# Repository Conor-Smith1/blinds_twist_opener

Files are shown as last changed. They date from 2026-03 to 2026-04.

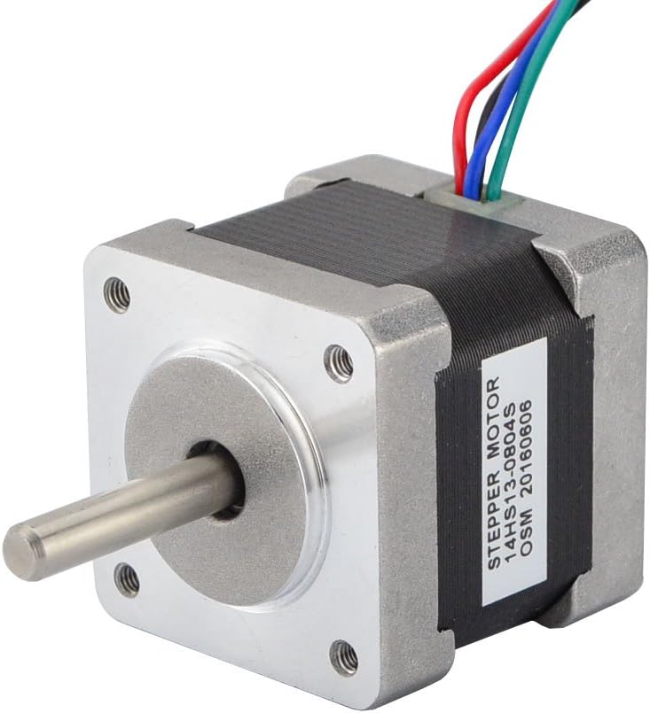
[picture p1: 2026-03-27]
Wiring Diagarm/NEMA14_Stepper.jpg

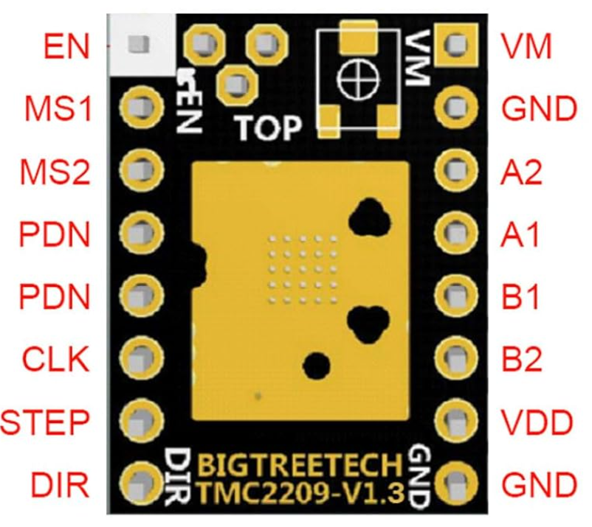
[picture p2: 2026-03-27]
Wiring Diagarm/TMC2209.png

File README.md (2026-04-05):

# Blinds Twist Opener

This project packages the pieces needed to motorize twist-style window blinds with an ESP32, a stepper motor, a hall effect home sensor, and a small 3D-printed enclosure/adapter set. The goal is to automate blinds without permanently modifying an apartment or rental space: the control box can be mounted with removable adhesive, and the printed coupler drives the existing blind wand/shaft.

## What is in this repository

- [`smartblinds.yaml`](smartblinds.yaml): ESPHome firmware for the ESP32, including homing, open/close/position control, and Home Assistant entities.
- [`3D Printer Models`](3D%20Printer%20Models): Printable `.stl` files for the enclosure and blind interface parts.
- [`CAD`](CAD): Source `.step` files for the printable parts.
- [`Wiring Diagarm`](Wiring%20Diagarm): WireViz source plus exported wiring images and reference photos.
- [`BoM.xlsx`](BoM.xlsx): Bill of materials with example parts and source links.

## Hardware overview

The included BOM and wiring files point to a build based on:

- ESP32 dev board
- TMC2209 stepper driver
- NEMA 14 bipolar stepper motor
- A3144 hall effect sensor
- 12 V power supply
- MP1584EN buck converter to power the ESP32
- 220 uF capacitor across the motor supply
- 10 mm x 3 mm magnet for homing
- 1/4 in aluminum rod plus jumper wiring

The spreadsheet title is "Home Assistant Ready Automated Twist Blind Opener", and the example parts list uses readily available hobby components rather than custom electronics.

## Wiring and pin map

The wiring diagram in [`Wiring Diagarm/smart_blinds_wireviz.yml`](Wiring%20Diagarm/smart_blinds_wireviz.yml) maps the ESP32 like this:

- `GPIO25`: motor enable
- `GPIO26`: step
- `GPIO27`: direction
- `GPIO33`: hall effect sensor output
- `3V3` / `GND`: hall sensor power
- `5V` / `GND`: ESP32 power from the buck converter

Power is split two ways:

- 12 V directly to the stepper driver motor supply (`VMOT` + `GND`)
- 12 V into the buck converter, reduced to 5 V for the ESP32

The motor driver is shown as a TMC2209, but the ESPHome config uses the `a4988` stepper platform. That is reasonable here because ESPHome is only generating `STEP`, `DIR`, and `EN` signals; the TMC2209 is effectively being treated like a standalone step/dir driver rather than configured over UART.

## Firmware behavior

The ESPHome config creates:

- A `cover` entity named `Bedroom Blinds`
- A `binary_sensor` named `Blind Home Sensor`
- A `sensor` named `Blind Position Percent`
- Buttons for `Home Blinds`, `Open One Turn`, and `Close One Turn`

On boot, the device automatically runs a homing script:

1. The motor is enabled.
2. The stepper position is seeded to a positive value.
3. The firmware searches toward the hall sensor in small negative moves.
4. Once the sensor triggers, it backs off by a configured close offset.
5. Position `0` is recorded as the fully closed reference point.

If homing never finds the sensor within the allowed travel window, the firmware sets a failure flag and stops the motor.

## Important tuning values

These values in [`smartblinds.yaml`](smartblinds.yaml) will likely need to be adjusted for your blinds and gearing:

- `steps_per_turn: 1600`
- `total_steps: 8000`
- `close_offset_steps: 2400`
- `max_speed: 1200 steps/s`
- `acceleration: 400`
- `deceleration: 400`

What they mean:

- `steps_per_turn`: how many motor steps make one full twist of the blind mechanism
- `total_steps`: full travel from closed to open
- `close_offset_steps`: how far to move after the hall sensor is detected so the blinds land on the true closed position

## How to use the ESPHome config

1. Copy or edit [`smartblinds.yaml`](smartblinds.yaml).
2. Replace the Wi-Fi placeholders with your SSID and password.
3. Update or remove the `manual_ip` block if it does not match your network.
4. Flash the ESP32 with ESPHome.
5. Verify the hall sensor polarity and motor direction before letting the blinds run a full cycle.
6. Tune `steps_per_turn`, `total_steps`, and `close_offset_steps` until the physical open/close positions match the reported cover position.

If the motor moves away from home during startup, reverse the motor direction in firmware or swap the appropriate motor wiring at the driver.

## Files you will probably want first

- Use [`smartblinds.yaml`](smartblinds.yaml) if you are building or modifying the firmware.
- Use [`Wiring Diagarm/smart_blinds_wireviz.svg`](Wiring%20Diagarm/smart_blinds_wireviz.svg) or [`Wiring Diagarm/smart_blinds_wireviz.png`](Wiring%20Diagarm/smart_blinds_wireviz.png) during assembly.
- Use the `.stl` files in [`3D Printer Models`](3D%20Printer%20Models) to print parts directly.
- Use the `.step` files in [`CAD`](CAD) if you want to modify the mechanical design.
- Use [`BoM.xlsx`](BoM.xlsx) if you want the original parts list and purchase references.

## Notes and assumptions

- The repository currently documents a single blind setup named `Bedroom Blinds`; you will probably want to rename entities for your room/device.
- The hall sensor input is configured with pull-up and inverted logic, with 20 ms debounce on both edges.
- The motor enable output is also inverted in firmware.
- This design appears intended for tilt/twist blinds, not lift-style blinds that raise and lower the whole shade.

## License

See [`LICENSE`](LICENSE).

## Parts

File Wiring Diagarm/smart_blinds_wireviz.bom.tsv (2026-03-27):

Id | Description | Qty | Unit | Designators
1 | Cable, 2 wires | 0 | m
2 | Cable, 3 wires | 0 | m
3 | Cable, 4 wires | 0 | m
4 | Cable, 5 wires | 0 | m
5 | Connector, 12V Power Supply, 2 pins | 1 |  | PSU_12V
6 | Connector, A3144 Hall Sensor, 3 pins | 1 |  | Hall_A3144
7 | Connector, ESP32 Dev Board, 7 pins | 1 |  | ESP32
8 | Connector, Electrolytic Capacitor, 2 pins | 1 |  | VMOT_Cap
9 | Connector, MP1584EN Buck Converter, 4 pins | 1 |  | Buck
10 | Connector, NEMA 14 Stepper Motor, 4 pins | 1 |  | Stepper
11 | Connector, TMC2209 Stepper Driver, 10 pins | 1 |  | TMC2209

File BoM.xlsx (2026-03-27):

Home Assistant Ready Automated Twist Blind Opener
Bill of Materials
Item # | ASIN | Product Title | Category | Short Description | Qty Used | Listing / Pack Qty | Source
1 | B01EV70C78 | ELEGOO 120pcs Multicolored Dupont Wire 40pin Male to Female, 40pin Male to Male, 40pin Female to Female Breadboard Jumper Ribbon Cables Kit Compatible with Arduino Projects | Jumper wires | 120-piece jumper wire kit; includes 40-pin male-to-female, male-to-male, and female-to-female ribbons; approx. 20 cm / 8 in each. | 30 | 120 pcs kit | https://www.amazon.com/dp/B01EV70C78?ref=ppx_yo2ov_dt_b_fed_asin_title
2 | B08D5ZD528 | ESP-WROOM-32 ESP32 ESP-32S Development Board 2.4GHz Dual-Mode WiFi + Bluetooth Dual Cores Microcontroller Processor Integrated with Antenna RF AMP Filter AP STA Compatible with Arduino IDE (3PCS) | Microcontroller board | ESP32 development board listing; 2.4 GHz Wi‑Fi + Bluetooth, dual core, Arduino IDE compatible. | 1 | 3 pcs | https://www.amazon.com/dp/B08D5ZD528?ref=ppx_yo2ov_dt_b_fed_asin_title&th=1
3 | B09S5SMFY4 | TRYMAG Small 10x3mm Rare Earth Magnets, 50Pcs Strong Neodymium Tiny Round Fridge Magnets for Whiteboard, Refrigerator, DIY, Kitchen, Office | Magnets | Neodymium round magnets, 10 mm diameter x 3 mm thick. | 1 | 50 pcs | https://www.amazon.com/dp/B09S5SMFY4?ref=ppx_yo2ov_dt_b_fed_asin_title&th=1
4 | B08SMDY3SQ | BIGTREETECH TMC2209 V1.3 UART Stepper Motor Driver 2.8A Peak Stepstick Silent Driver for Manta M8P, Octopus V1.1, Octopus Pro, SKR 3, SKR V1.4 Turbo, SKR Pro V1.2 3D Printer Control Board (2 PCS) | Stepper motor driver | TMC2209 V1.3 UART stepper driver; supports STEP/DIR and UART mode; 2.8 A peak listing. | 1 | 2 pcs | https://www.amazon.com/dp/B08SMDY3SQ?ref=ppx_yo2ov_dt_b_fed_asin_title&th=1
5 | B01GD4ZQRS | inShareplus 12V Power Supply, 12 Voltage 2A 24W Switching Power Supply, Drive, Power Adapter, AC 110V to 12 Volt Power Supply for LED Strip Light with 5.5/2.1mm DC Female Barrel Connector | Power supply | AC 100–240 V to DC 12 V 2 A / 24 W switching power supply with 5.5/2.1 mm DC female barrel connector. | 1 | 1 unit | https://www.amazon.com/dp/B01GD4ZQRS?ref=ppx_yo2ov_dt_b_fed_asin_title&th=1
6 | B0CMQFGLTQ | 220uF 10V 5x11mm Electrolytic Capacitor 220 UF MFD 10 Volt 0.2x0.43in Aluminum Capacitors (Pack of 15) | Electrolytic capacitor | Aluminum electrolytic capacitor, 220 µF, 10 V, approx. 5 x 11 mm. | 1 | 15 pcs | https://www.amazon.com/dp/B0CMQFGLTQ?ref=ppx_yo2ov_dt_b_fed_asin_title&th=1
7 | B0B779ZYN1 | MP1584EN 5pcs Mini 5V Buck Converter Board - 5-30V to 5V, 1.8A Output, Small Size, Black | Buck converter | Mini buck converter board; 5–30 V input to 5 V output; up to 1.8 A; small form factor. | 1 | 5 pcs | https://www.amazon.com/dp/B0B779ZYN1?ref=ppx_yo2ov_dt_b_fed_asin_title&th=1
8 | B0CZ6QXMZ2 | 20Pcs A3144 3144 Hall Effect Sensor OH3144 AH3144E 3Pins Magnetic Detector | Hall effect sensor | A3144 / OH3144 / AH3144E 3-pin Hall effect magnetic detector. | 1 | 20 pcs | https://www.amazon.com/dp/B0CZ6QXMZ2?ref=ppx_yo2ov_dt_b_fed_asin_title&th=1
9 | B00PQ4Y9B6 | STEPPERONLINE Nema 14 Bipolar Stepper Motor 0.8A 25.5oz.in/18Ncm 3D Printer CNC Machine | Stepper motor | NEMA 14 bipolar stepper motor; 0.8 A; 18 N·cm (25.5 oz-in) holding torque; 1.8° step angle. | 1 | 1 unit | https://www.amazon.com/dp/B00PQ4Y9B6?ref=ppx_yo2ov_dt_b_fed_asin_title
10 | ----- | 1/4" OD Aluminum Rod 1 meter length | Rod | 1/4" Aluminum Rod | 1 | ---- | Hardware Store

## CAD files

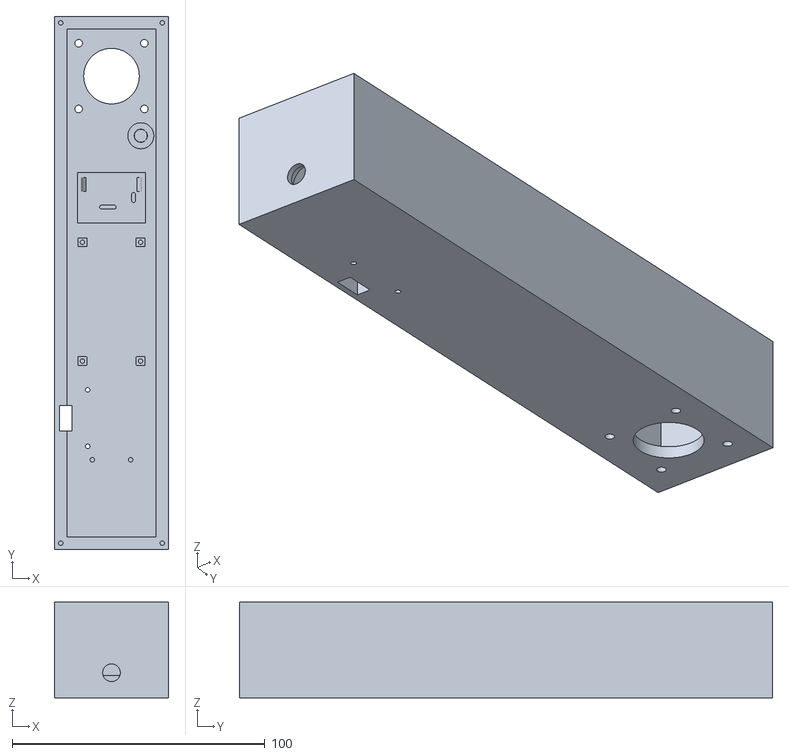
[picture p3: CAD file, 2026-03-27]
3D Printer Models/14HS13-0804S - Main Case.stl
45.2 x 211.0 x 38.0

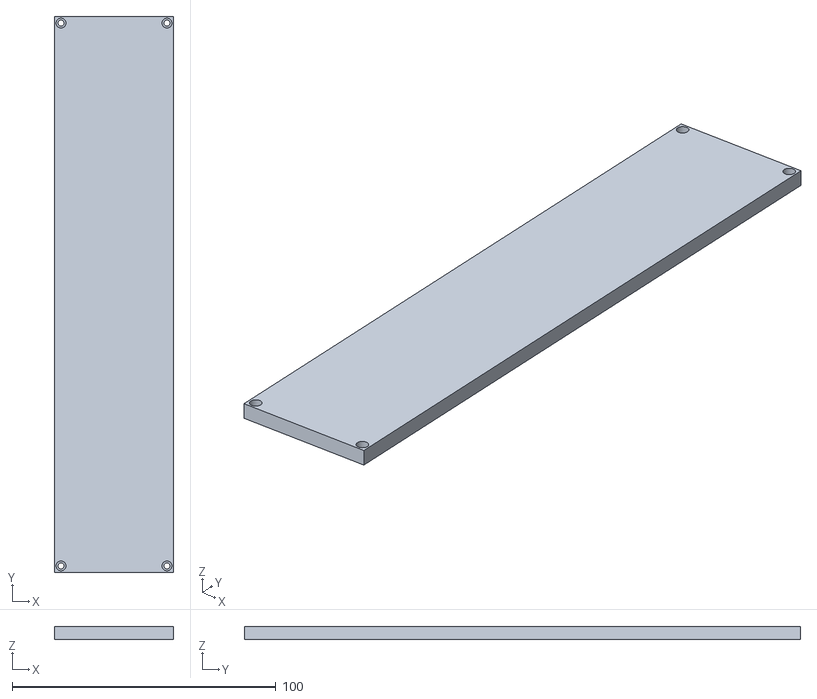
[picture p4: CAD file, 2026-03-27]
3D Printer Models/14HS13-0804S - Bottom.stl
45.2 x 211.0 x 5.00

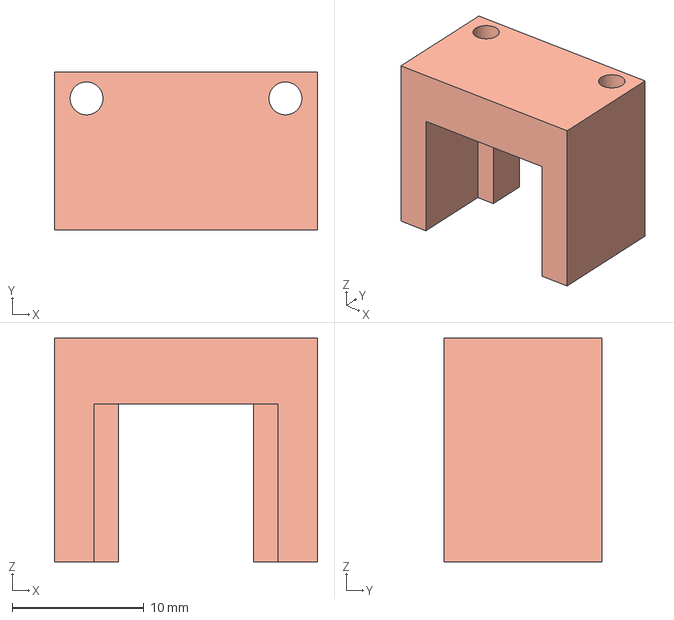
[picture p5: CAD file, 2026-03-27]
CAD/14HS13-0804S - Power Holddown.step
20.0 x 12.0 x 17.0 mm

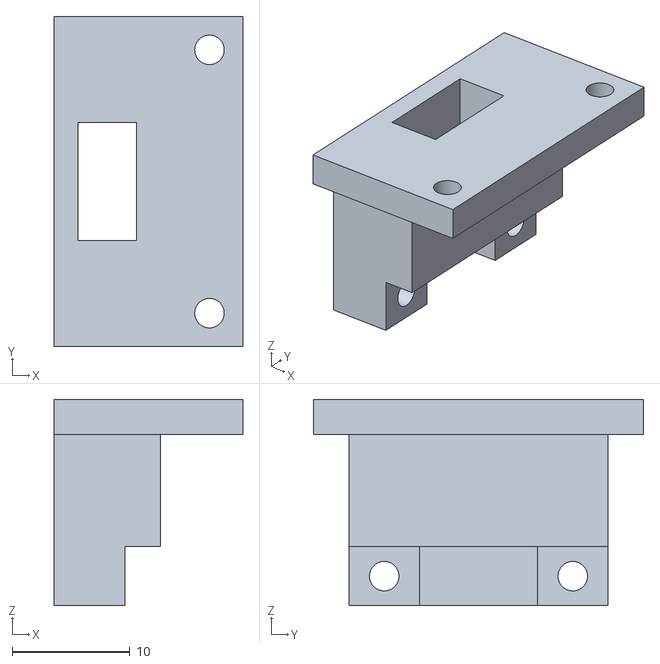
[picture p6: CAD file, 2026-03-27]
3D Printer Models/14HS13-0804S - Hall Effect Tower Base.stl
16.0 x 28.0 x 17.5

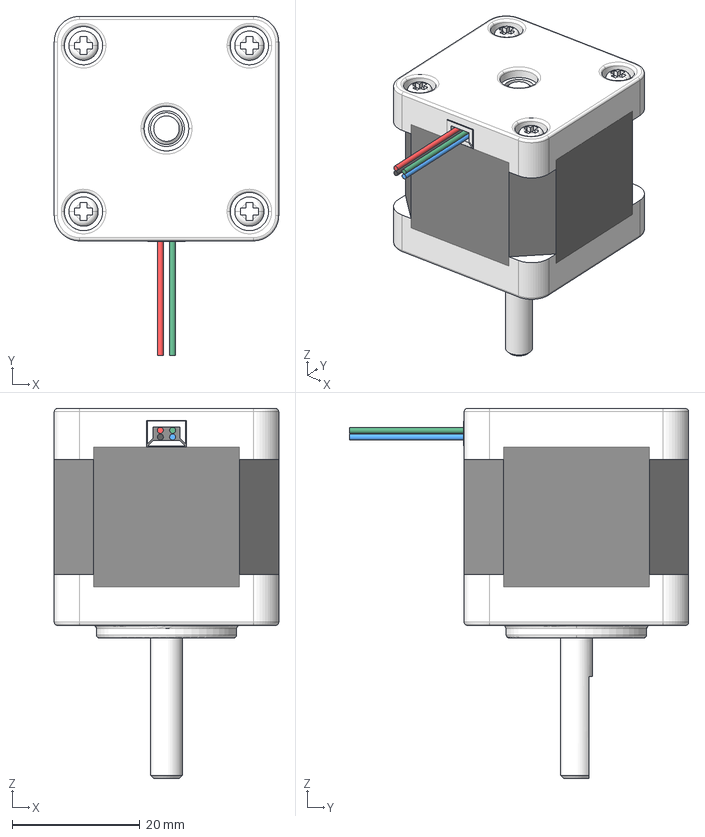
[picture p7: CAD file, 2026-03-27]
CAD/14HS13-0804S - 14HS13-0804S.step
35.2 x 53.2 x 58.0 mm

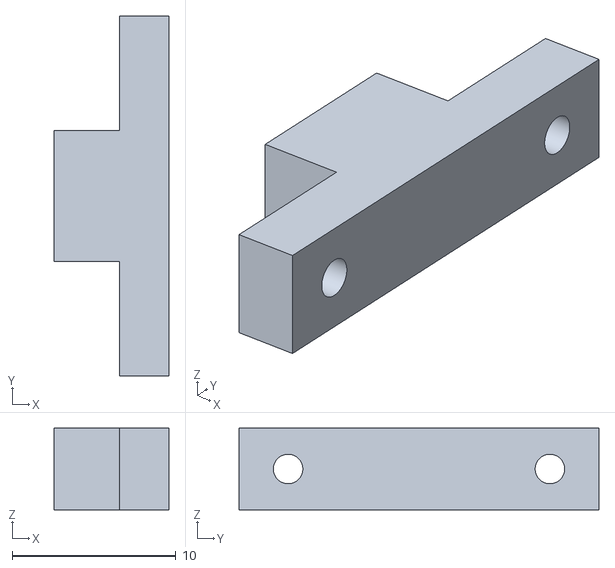
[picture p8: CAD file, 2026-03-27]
3D Printer Models/14HS13-0804S - Hall Effect Pinch.stl
7.00 x 22.0 x 5.00

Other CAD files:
CAD/14HS13-0804S - Main Case.step
CAD/14HS13-0804S - Bottom.step
3D Printer Models/14HS13-0804S - Power Holddown.stl
CAD/14HS13-0804S - Hall Effect Tower Base.step
CAD/14HS13-0804S - Hall Effect Pinch.step

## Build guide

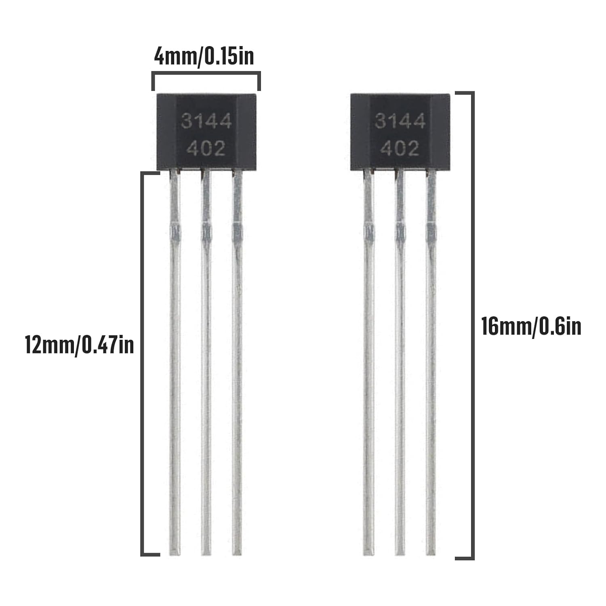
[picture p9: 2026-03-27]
Wiring Diagarm/A3144_Hall_Effect.jpg

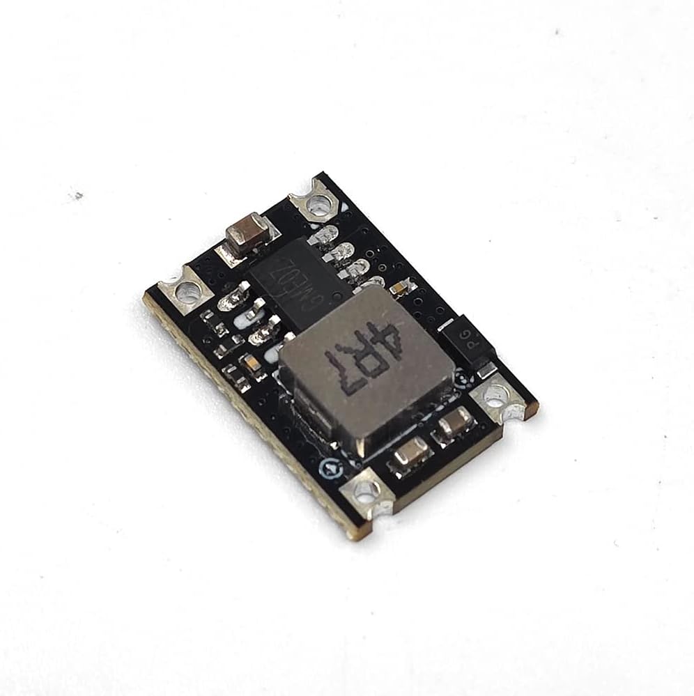
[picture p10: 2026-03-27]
Wiring Diagarm/MP1584EN_Buck_Converter.jpg

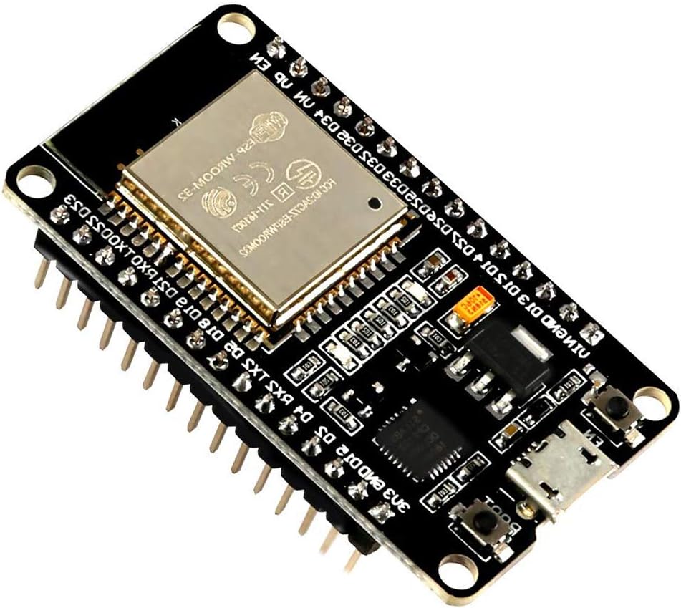
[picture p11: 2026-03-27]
Wiring Diagarm/ESP32.jpg

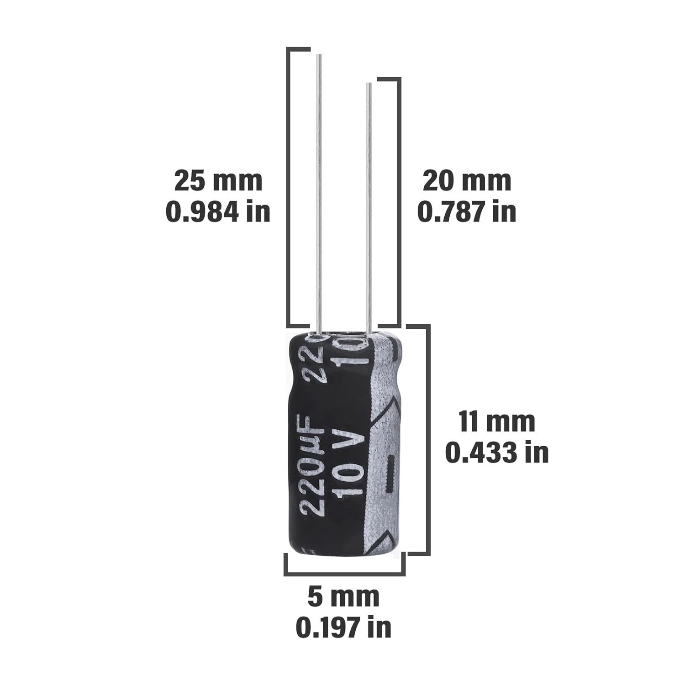
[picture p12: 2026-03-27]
Wiring Diagarm/220uF_Electrolytic.jpg

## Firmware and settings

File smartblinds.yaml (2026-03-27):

esphome:
  name: smart-blinds
  friendly_name: Smart Blinds
  on_boot:
    priority: -10
    then:
      - script.execute: home_blinds

esp32:
  board: esp32dev
  framework:
    type: esp-idf

wifi:
  ssid: "<SSID HERE>"
  password: "<PASSWORD HERE>"
  manual_ip:
    static_ip: 192.168.50.55
    gateway: 192.168.50.1
    subnet: 255.255.255.0

logger:

api:

ota:
  - platform: esphome

output:
  - platform: gpio
    id: stepper_enable
    pin:
      number: GPIO25
      inverted: true

binary_sensor:
  - platform: gpio
    id: blind_home
    name: "Blind Home Sensor"
    pin:
      number: GPIO33
      mode:
        input: true
        pullup: true
      inverted: true
    filters:
      - delayed_on: 20ms
      - delayed_off: 20ms

stepper:
  - platform: a4988
    id: blind_stepper
    step_pin: GPIO26
    dir_pin:
      number: GPIO27
      inverted: true
    max_speed: 1200 steps/s
    acceleration: 400
    deceleration: 400

globals:
  - id: steps_per_turn
    type: int
    restore_value: no
    initial_value: '1600'

  - id: total_steps
    type: int
    restore_value: no
    initial_value: '8000'

  - id: close_offset_steps
    type: int
    restore_value: no
    initial_value: '2400'

  - id: current_target
    type: int
    restore_value: yes
    initial_value: '0'

  - id: is_homed
    type: bool
    restore_value: no
    initial_value: 'false'

  - id: home_failed
    type: bool
    restore_value: no
    initial_value: 'false'

script:
  - id: enable_motor
    mode: restart
    then:
      - output.turn_on: stepper_enable
      - delay: 100ms

  - id: disable_motor
    mode: restart
    then:
      - delay: 500ms
      - output.turn_off: stepper_enable

  - id: home_blinds
    mode: restart
    then:
      - logger.log: "Starting homing"
      - lambda: |-
          id(home_failed) = false;
          id(is_homed) = false;
      - script.execute: enable_motor

      # Start from a positive position so we can search negative toward home
      - stepper.report_position:
          id: blind_stepper
          position: 5000
      - stepper.set_target:
          id: blind_stepper
          target: 5000

      # Search toward hall trigger with bounded travel
      - repeat:
          count: 400
          then:
            - if:
                condition:
                  binary_sensor.is_on: blind_home
                then:
                  - logger.log: "Hall sensor triggered, applying close offset"
                  - stepper.set_target:
                      id: blind_stepper
                      target: !lambda 'return id(blind_stepper).current_position - id(close_offset_steps);'
                  - wait_until:
                      condition:
                        lambda: 'return id(blind_stepper).current_position == id(blind_stepper).target_position;'
                      timeout: 60s
                  - stepper.report_position:
                      id: blind_stepper
                      position: 0
                  - stepper.set_target:
                      id: blind_stepper
                      target: 0
                  - lambda: |-
                      id(current_target) = 0;
                      id(is_homed) = true;
                  - logger.log: "Homing complete"
                  - script.execute: disable_motor
                  - script.stop: home_blinds

            - stepper.set_target:
                id: blind_stepper
                target: !lambda 'return id(blind_stepper).target_position - 20;'
            - delay: 50ms

      - logger.log: "ERROR: homing failed before max travel"
      - lambda: |-
          id(home_failed) = true;
      - stepper.set_target:
          id: blind_stepper
          target: !lambda 'return id(blind_stepper).current_position;'
      - script.execute: disable_motor

button:
  - platform: template
    name: "Home Blinds"
    on_press:
      - script.execute: home_blinds

  - platform: template
    name: "Open One Turn"
    on_press:
      - script.execute: enable_motor
      - lambda: |-
          id(current_target) = id(blind_stepper).current_position + id(steps_per_turn);
      - stepper.set_target:
          id: blind_stepper
          target: !lambda 'return id(current_target);'
      - wait_until:
          condition:
            lambda: 'return id(blind_stepper).current_position == id(blind_stepper).target_position;'
          timeout: 30s
      - script.execute: disable_motor

  - platform: template
    name: "Close One Turn"
    on_press:
      - script.execute: enable_motor
      - lambda: |-
          id(current_target) = id(blind_stepper).current_position - id(steps_per_turn);
      - stepper.set_target:
          id: blind_stepper
          target: !lambda 'return id(current_target);'
      - wait_until:
          condition:
            lambda: 'return id(blind_stepper).current_position == id(blind_stepper).target_position;'
          timeout: 30s
      - script.execute: disable_motor
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

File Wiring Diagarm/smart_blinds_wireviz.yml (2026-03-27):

metadata:
  title: Smart Blinds Wiring (ESP32 + TMC2209)

connectors:

  # --- TOP: Hall sensor ---
  Hall_A3144:
    type: A3144 Hall Sensor
    pinlabels: ["VCC", "GND", "OUT"]
    image:
      src: A3144_Hall_Effect.jpg
      height: 60
      caption: Hall Sensor

  # --- Power supply ---
  PSU_12V:
    type: 12V Power Supply
    pinlabels: ["+12V", "GND"]

  # --- Buck converter ---
  Buck:
    type: MP1584EN Buck Converter
    pinlabels: ["IN+", "IN-", "OUT+", "OUT-"]
    image:
      src: MP1584EN_Buck_Converter.jpg
      height: 70
      caption: Buck Converter

  # --- ESP32 ---
  ESP32:
    type: ESP32 Dev Board
    pinlabels: ["5V", "3V3", "GND", "GPIO25", "GPIO26", "GPIO27", "GPIO33"]
    image:
      src: ESP32.jpg
      height: 90
      caption: ESP32

  # --- Stepper driver ---
  TMC2209:
    type: TMC2209 Stepper Driver
    pinlabels: ["EN", "STEP", "DIR", "VIO", "GND", "VMOT", "A1", "A2", "B1", "B2"]
    image:
      src: TMC2209.png
      height: 90
      caption: TMC2209

  # --- Bulk capacitor ---
  VMOT_Cap:
    type: Electrolytic Capacitor
    pinlabels: ["+", "-"]
    image:
      src: 220uF_Electrolytic.jpg
      height: 70
      caption: 220uF VMOT Capacitor

  # --- BOTTOM: Stepper motor ---
  Stepper:
    type: NEMA 14 Stepper Motor
    pinlabels: ["A+", "A-", "B+", "B-"]
    image:
      src: NEMA14_Stepper.jpg
      height: 90
      caption: Stepper Motor


cables:

  PSU_to_Buck:
    wirecount: 2
    colors: ["RD", "BK"]
    show_name: false

  PSU_to_TMC:
    wirecount: 2
    colors: ["RD", "BK"]
    show_name: false

  Buck_to_ESP32:
    wirecount: 2
    colors: ["RD", "BK"]
    show_name: false

  ESP32_to_TMC_ctrl:
    wirecount: 5
    colors: ["GN", "YE", "BU", "OG", "BK"]
    show_name: false

  ESP32_to_Hall:
    wirecount: 3
    colors: ["RD", "BK", "VT"]
    show_name: false

  TMC_to_Stepper:
    wirecount: 4
    colors: ["RD", "BU", "GN", "BK"]
    show_name: false

  Cap_to_TMC:
    wirecount: 2
    colors: ["RD", "BK"]
    show_name: false


connections:

  # Hall sensor at top
  -
    - ESP32: ["3V3", "GND", "GPIO33"]
    - ESP32_to_Hall: [1, 2, 3]
    - Hall_A3144: ["VCC", "GND", "OUT"]

  # PSU → Buck
  -
    - PSU_12V: ["+12V", "GND"]
    - PSU_to_Buck: [1, 2]
    - Buck: ["IN+", "IN-"]

  # PSU → Driver VMOT
  -
    - PSU_12V: ["+12V", "GND"]
    - PSU_to_TMC: [1, 2]
    - TMC2209: ["VMOT", "GND"]

  # Capacitor across VMOT
  -
    - TMC2209: ["VMOT", "GND"]
    - Cap_to_TMC: [1, 2]
    - VMOT_Cap: ["+", "-"]

  # Buck → ESP32 power
  -
    - Buck: ["OUT+", "OUT-"]
    - Buck_to_ESP32: [1, 2]
    - ESP32: ["5V", "GND"]

  # ESP32 → Driver control
  -
    - ESP32: ["GPIO25", "GPIO26", "GPIO27", "3V3", "GND"]
    - ESP32_to_TMC_ctrl: [1, 2, 3, 4, 5]
    - TMC2209: ["EN", "STEP", "DIR", "VIO", "GND"]

  # Driver → Stepper (bottom)
  -
    - TMC2209: ["A1", "A2", "B1", "B2"]
    - TMC_to_Stepper: [1, 2, 3, 4]
    - Stepper: ["A+", "A-", "B+", "B-"]
